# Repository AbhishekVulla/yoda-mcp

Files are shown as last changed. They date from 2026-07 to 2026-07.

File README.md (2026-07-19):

# Yoda

A voice-first care necklace for elderly people living alone. She talks to it. It talks to her caregiver.

**[Demo video](https://www.youtube.com/watch?v=fLG9y0mhrLA)** · Top 5 Finalist, Dell InnovateDash 2026 (Care Corner)

> The wake word is "Jarvis". Espressif only ships a handful of pre-trained wake words and "Yoda" isn't one of them, so the repo kept the original name.

## Why

Singapore's community care services do exist. They are just scattered across portals, hotlines and 20-question intake forms, and the people who need them most are the least likely to get through an app to reach them. Someone who can talk to a necklace does not have to navigate any of that, and her caregiver still makes every decision.

## What it does

**Daily check-in.** The necklace starts a short recovery check-in on its own, tailored to what's on her record. Did you take your heart medicine. How's the cut on your chest. Any tightness or trouble breathing. Her answers become a health incident, and the dashboard turns that into an SBAR clinical handover a caregiver or a paramedic can actually act on.

**Welfare escalation.** If a caregiver can't reach her at the door or by phone, they ping the necklace from the dashboard. It beeps and asks her to respond. Only if she doesn't answer does the camera unlock, and only after the necklace has said out loud that it's turning on.

One rule underneath both: **the AI never acts alone.** Every action it wants to take becomes a request a human approves first.

## Architecture

```mermaid
flowchart LR
  Senior([Senior]) -->|voice| Pendant[Necklace<br/>XIAO ESP32-S3<br/>· firmware/ ·]
  Pendant -->|audio, MQTT+UDP| Cloud[xiaozhi.me<br/>ASR · LLM · TTS]
  Cloud <-->|MCP tool calls| Server[MCP server<br/>· repo root ·]
  Server --> Neon[(Neon Postgres)]
  Dash[Caregiver dashboard<br/>· dashboard/ ·] <--> Neon
  Dash -->|synthesize SBAR| LLM2[OpenAI]
  Pendant <-.->|poll for ping/camera<br/>push JPEG frames| Dash
  Caregiver([Caregiver]) --> Dash
```

The cloud LLM is the only thing that calls the tools. The dashboard and the MCP server never talk to each other directly, they meet at the database.

## The parts that were actually hard

**The MCP server dials out.** A hosted LLM can't reach a tool server sitting on a laptop behind NAT. So `mcp_pipe.py` opens the WebSocket in the other direction, to the cloud's MCP endpoint, and pipes it to a local stdio FastMCP process. No port forwarding, no public IP, no tunnel service.

**The emergency watchdog is a SQL expression, not a worker.** If she starts a health check and then goes quiet, that silence has to become an alert. Instead of a cron job or a background queue, the escalation is derived at query time:

```sql
CASE WHEN status = 'in_progress' AND now() - started_at > make_interval(secs => 25)
     THEN 'emergency' ...
```

The dashboard already polls every 3s, so the escalation just appears. Nothing to schedule, nothing to keep alive, nothing to crash silently.

**Seeing her from anywhere, with zero setup.** The first version needed the caregiver on the same Wi-Fi to reach the necklace's LAN server. Useless in practice. Now the necklace polls the dashboard for commands and pushes JPEG frames up over HTTPS, so everything is outbound. Works on a mobile hotspot, no router config.

**That relay was quietly killing the wake word.** After adding the relay, "Jarvis" stopped triggering. The cause was a fresh TLS handshake every 2 seconds hogging the CPU and starving the on-chip wake-word detector, which needs a steady mic feed. Throttling the idle poll to 15s brought it back. The camera stream still starves it while running, which is fine, that path is caregiver-initiated.

**Privacy is enforced on the device, not the dashboard.** The camera can't be turned on cold. It only unlocks after a ping goes unanswered, and the necklace speaks an announcement before the lens opens.

## What's real and what's mocked

Real: the voice loop, the tool calls, the database, the triage and escalation, the SBAR report, the camera relay, the firmware.

Mocked: the service providers. No Singapore community-care provider (Care Corner, AIC/ICCP, Meals-on-Wheels) exposes a public booking API, it's all phone, email and referral forms. The tools return realistic results and `services.py` keeps a one-function seam to drop in a real `httpx` call the day an API exists.

Also worth saying plainly: the firmware is a custom board overlay on [`78/xiaozhi-esp32`](https://github.com/78/xiaozhi-esp32) (MIT), not a from-scratch stack. The board definition, welfare HTTP API, cloud relay and camera path are mine.

## Repo layout

```
yoda-mcp/
├── yoda_iccp.py          # the 8 tools the cloud LLM can call
├── mcp_pipe.py           # dials OUT to the cloud MCP endpoint
├── health_db.py          # triage + the no-response escalation
├── kb_store.py           # senior profile load/merge (Neon or local file)
├── events.py             # activity matching
├── services.py           # mock provider adapter (the real-API seam)
├── SYSTEM_PROMPT.md      # the agent prompt, pasted into the xiaozhi console
├── test_*.py             # 14 tests
│
├── firmware/yoda-pendant/    # board overlay: config, welfare HTTP API, cloud relay
├── dashboard/                # Next.js caregiver dashboard
│   ├── app/                  # care view, welfare panel, SBAR report page
│   └── lib/                  # Neon queries + OpenAI report synthesis
└── cad/pendant_case.py       # parametric enclosure (build123d) -> printable STL
```

## The tools

| Tool | What it does |
|---|---|
| `get_senior_profile` | Recall who it's talking to. Called first, so it never re-asks what's on file. |
| `begin_health_check` | Open an incident the moment she reports feeling unwell. Starts the silence timer. |
| `complete_health_check` | File the triage with clinical red flags → `mild` / `serious` |
| `match_events` | Top 1-2 activities for her goals and area, excluding ones already requested |
| `request_activity` | Create a **pending request** for the caregiver. Never books directly. |
| `update_knowledge_base` | Save preferences learned in conversation |
| `get_onboarding_questions` | Short sign-up questions, only what isn't already known |
| `book_meal_delivery` | Mock meal booking |

## Run it

**MCP server** (repo root)

```bash
python -m venv .venv && .venv\Scripts\activate
pip install -r requirements.txt
# .env:  MCP_ENDPOINT=wss://api.xiaozhi.me/mcp/?token=...
#        DATABASE_URL=postgresql://...
python mcp_pipe.py yoda_iccp.py
```

Then paste `SYSTEM_PROMPT.md` into the xiaozhi.me console as the agent's role and hit Refresh on the MCP endpoint. Run only one MCP server at a time.

**Dashboard**

```bash
cd dashboard && npm install
# .env.local:  DATABASE_URL=...  OPENAI_API_KEY=...
npm run dev
```

**Tests**

```bash
pytest          # 14 tests: matching, KB merge, services, triage + escalation
```

## Security

`MCP_ENDPOINT`, `DATABASE_URL` and `OPENAI_API_KEY` live in `.env` / `.env.local`, both gitignored and never committed. The device token in `firmware/yoda-pendant/config.h` is a placeholder in this repo. Rotate the MCP token from the console if it ever leaks.

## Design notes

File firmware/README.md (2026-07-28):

# Pendant firmware

A XIAO ESP32-S3 Sense running the [xiaozhi-esp32](https://github.com/78/xiaozhi-esp32) voice
stack, plus a custom board (`yoda-pendant`) that adds the caregiver welfare check.

This folder is an **overlay, not a full firmware tree**. Upstream is ~18k files of MIT code, and
vendoring it here would bury the part that is actually ours. So this holds only our files, applied
onto a clean upstream checkout.

## What's ours

| Path | What it is |
|---|---|
| `yoda-pendant/config.h` | Pin map: I2S speaker (MAX98357A), PDM mic, camera, boot button, cloud relay config |
| `yoda-pendant/config.json` | Build target and sdkconfig (8 MB flash, EN_US, "Jarvis" wake word) |
| `yoda-pendant/yoda_pendant_board.cc` | The board: voice stack, LAN HTTP server, and the cloud relay loop |
| `assets/checking.ogg` | "We're checking on you now" privacy announce, played before the camera arms |
| `assets/door.ogg` | Legacy ping announce |
| `patches/esp32_camera.{h,cc}.patch` | Adds `CaptureToJpeg` and a lean `CaptureJpegStream` for MJPEG |
| `patches/CMakeLists.txt.patch` | Registers `BOARD_TYPE_YODA_PENDANT` |
| `patches/Kconfig.projbuild.patch` | Adds the board to the menuconfig list |
| `scripts/` | Build, flash and serial helpers (Windows) |

## Hardware

XIAO ESP32-S3 Sense: onboard camera (OV2640 or OV3660 depending on the batch, same Seeed pinout),
onboard PDM mic, 2.4 GHz WiFi, USB-CDC.

**MAX98357A I2S amp.** Note the silk labels on the XIAO are not GPIO numbers:

| Amp pin | GPIO | XIAO pad | Notes |
|---|---|---|---|
| LRC / WS | 1 | D0 | |
| BCLK | 2 | D1 | |
| DIN | 3 | D2 | |
| VIN | | 3V3 | |
| GND | | GND | must share ground with the XIAO |
| SD | | *(see below)* | shutdown + channel select, not optional |
| GAIN | | *(leave floating)* | floating gives the default gain |

These three GPIOs are the ones the board actually drives, so they have to match however the amp is
physically wired. If you rewire it, change `config.h` to suit, not the other way round.

**The SD pin is the one that bites you.** It is not just an on/off pin, it also picks the channel, and
the chip reads it as an analog voltage:

- Near 0 V (below ~0.16 V) the amp is in **full shutdown**. I2S keeps streaming, the ESP32 logs look
  perfect, and the speaker is completely silent. This is the classic false alarm: it looks like a
  software bug and it is not.
- Above roughly 1.4 V it plays the **left** channel. Mid voltages select right or a L+R mix.

Most of these breakouts have a pull-up so SD floats high on its own. Do not assume it. If there is any
doubt, jumper **SD to VIN** and the amp is forced awake on the left channel. The firmware sends the
same mono audio on both slots (`I2S_STD_SLOT_BOTH` in `yoda_pendant_board.cc`), so whichever channel
SD selects, there is audio in it.

**Speaker wiring.** The speaker's two wires go under the screws of the green terminal. If your speaker
came with a JST plug on the end, that plug does **not** mate with a screw terminal. Cut it off, strip
the wires, and clamp bare copper under the screws. A plug resting against the terminal reads as
"connected" by eye and passes no current.

PDM mic is on GPIO 42 (clock) and 41 (data). Wake word is "Jarvis", the stock WakeNet
`wn9_jarvis_tts` model. "Yoda" would need Espressif's paid custom training.

### Silent speaker, healthy logs

If the serial log reaches `State: speaking` and prints `<< ...` lines with no `EspUdp` or `MQTT`
errors, the whole software path is fine: mic, ASR, LLM, TTS and audio transport all worked. That says
nothing about which physical pins the audio is leaving on, or what happens after the amp. Work down
this list, in order:

1. **Pin map mismatch.** The three GPIOs above must match how the amp is actually wired. If they
   don't, the chip clocks I2S out of pins with nothing attached and every log line still looks
   perfect. Check this before touching the hardware.
2. **SD pin** at 0 V or floating low, so the amp is shut down (see above).
3. **Speaker not actually clamped** in the screw terminal (see above).
4. **Ground not common** between amp and XIAO.
5. **No power on VIN.**
6. **Blown speaker.** A 1 W driver run at high volume dies quickly, so keep the volume low while
   testing.

A useful splitter: with the amp powered, briefly tap the `DIN` pin to 3.3 V and back. A live amp and a
live speaker will click or pop audibly. Clicks mean the analog side is fine and the problem is
upstream. No clicks at all means the amp is asleep, unpowered, or not connected to the speaker.

## Two ways the caregiver reaches the necklace

**Cloud relay (the one that matters).** The necklace polls the deployed dashboard for pending
commands and pushes JPEG frames back up, both outbound over HTTPS. No port forwarding, no LAN
discovery, no public IP. It works on a mobile hotspot. Configured by `YODA_CLOUD_BASE` /
`YODA_DEVICE_TOKEN` in `config.h`, hitting `/api/device/poll` and `/api/device/frame`.

The idle poll is deliberately slow (15 s). A faster poll means a fresh TLS handshake every cycle,
which starves the on-chip wake-word detector of CPU and stops "Jarvis" triggering at all. That bug
cost a while to find, so the interval is load-bearing, not arbitrary.

**LAN HTTP server (fallback).** Kept for same-WiFi debugging.

| Endpoint | Effect |
|---|---|
| `GET /ping` | Beep and announce, asking her to respond |
| `GET /camera/on` | Privacy announce, then arm the camera |
| `GET /capture` | One JPEG still, only when armed |
| `GET /stream` | Live MJPEG until the client disconnects |
| `GET /camera/off` | Disarm, stream loop exits |

Camera frames are gated behind `/camera/on` by design. The caregiver cannot see anything until the
necklace has said out loud that it is turning on.

## Build from scratch

Needs ESP-IDF v5.5.x (built against 5.5.2).

```powershell
git clone https://github.com/78/xiaozhi-esp32.git
cd xiaozhi-esp32
powershell -File ..\yoda-mcp\firmware\apply-overlay.ps1 -XiaozhiRoot .
python scripts\release.py yoda-pendant
```

The wake word and 8 MB flash config come from `config.json`'s `sdkconfig_append`, so a clean build
is already set to Jarvis with no manual menuconfig.

```powershell
idf.py -p COM5 flash        # COM5 is single-access, close any serial monitor first
pio device monitor -p COM5 -b 115200
```

On boot the log prints the device's LAN IP for the fallback path:
`=== JARVIS WELFARE: device IP = 10.x.x.x ===`

> The `scripts/*.bat` helpers hard-code local paths (ESP-IDF under `C:\Users\...`). They are
> committed as a record of how this machine builds. Edit the paths for another environment, or use
> the raw `idf.py` commands above.

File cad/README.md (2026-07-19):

# Pendant case (XIAO ESP32-S3 Sense)

Parametric enclosure, printed in two parts. Every dimension is a number at the top of
`pendant_case.py`, so a bad test fit is a one-line change and a re-run, not a CAD session.

## Files

`pendant_case.py` is the model. It writes `pendant_base` and `pendant_lid` as both `.stl`
(slice these) and `.step` (edit these). `viewer.html` is a three.js preview, `preview.png`
is a static render.

## Regenerate

```bash
cd yoda-mcp
cad/.venv/Scripts/python.exe cad/pendant_case.py
```

Exports are vertex-merged and watertight-checked on the way out. A non-manifold edge fails
loudly here instead of halfway through a slicer.

## Preview in a browser

```bash
cd yoda-mcp/cad
.venv/Scripts/python.exe -m http.server 8000
# open http://localhost:8000/viewer.html
```

## What it holds

Interior 26 x 36 x 26 mm, outer 30 x 31 x 40 mm. That fits the XIAO ESP32-S3 Sense stack
(21 x 17.8 x 15), a 30 x 20 x 4.2 speaker, and a MAX98357 amp, stacked front to back.

The lid closes on a mid-wall spigot lip plus two diagonal M2 screws. The lip sits in the
middle of the wall rather than flush with the cavity, which keeps it clear of the screw
bosses and avoids the coincident faces that produce non-manifold geometry.

Camera hole is 7 mm (6 mm lens plus clearance), placed high so it clears the lanyard boss.
Three 2 mm holes below it vent the speaker and double as the mic opening. USB-C exits the
bottom edge.

## Printing

PLA, 0.2 mm layers, 3 walls, 15% infill. No supports needed: print the tub open side up and
the lid face down. Two M2 self-tapping screws, 6 to 8 mm.

## Tuning after a test fit

| Symptom | Parameter |
|---|---|
| Board will not drop in, or rattles | `BAYS["compact"]`, `WALL` |
| Camera hole misaligned | `CAM_OFF_X` (right is +), `CAM_OFF_Z` (up is +) |
| USB-C will not seat | `USB_OFF_X`, `USB_OFF_Y`, `USB_W`, `USB_H` |
| Lid too tight or too loose | `GROOVE_CLR` |
| Screws bind | `SCREW_CLEAR`, `SCREW_PILOT` |

`LAYOUT = "breadboard"` swaps in a larger bay if the amp is on a breadboard instead of
soldered.

## Known gaps

No board-retention ledge yet, the closed lid holds the board down. No dedicated antenna
channel either, the flat u.FL antenna tucks against an inside wall. Both are fine at this
size and worth adding once a print confirms the fit.

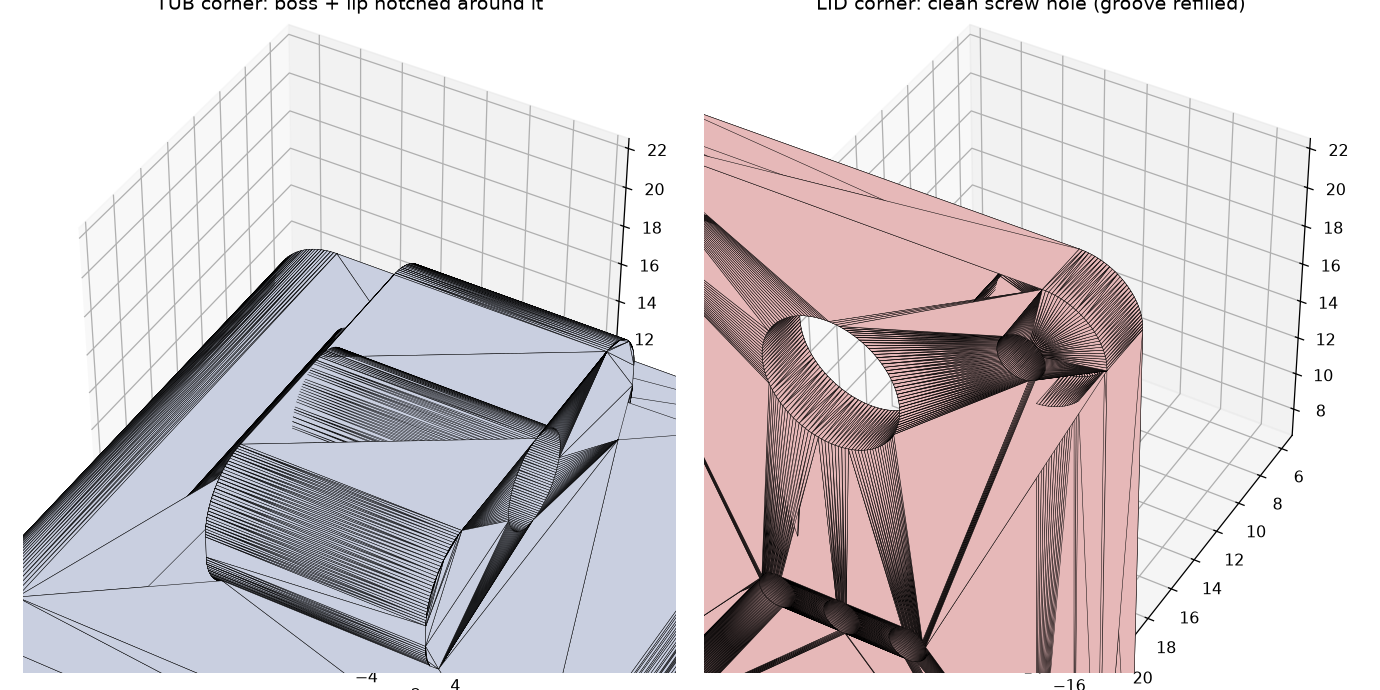
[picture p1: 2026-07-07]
cad/preview.png

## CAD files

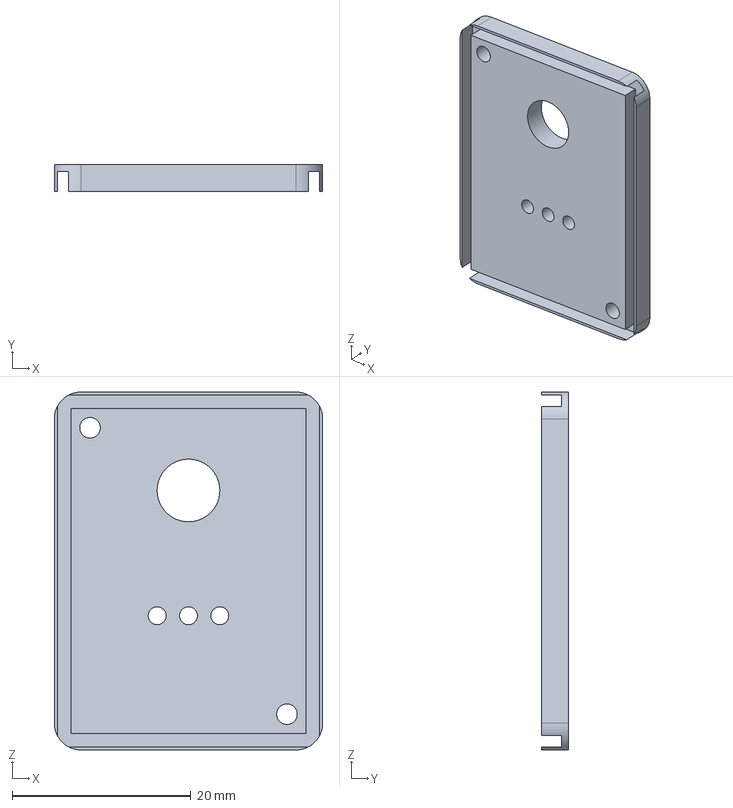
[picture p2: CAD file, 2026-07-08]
cad/pendant_lid.step
30.0 x 3.00 x 40.0 mm

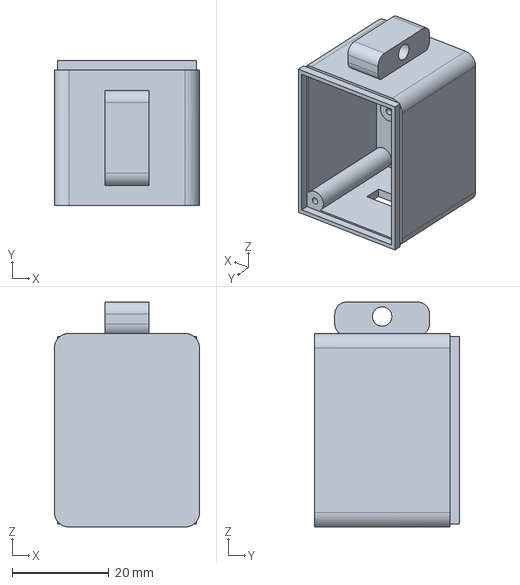
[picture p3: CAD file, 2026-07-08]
cad/pendant_base.step
30.0 x 30.0 x 46.5 mm

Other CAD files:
cad/pendant_base.stl
cad/pendant_lid.stl

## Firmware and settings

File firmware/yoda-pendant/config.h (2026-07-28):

#ifndef _BOARD_CONFIG_H_
#define _BOARD_CONFIG_H_

#include <driver/gpio.h>

// ===================== Yoda Pendant =====================
// Seeed XIAO ESP32-S3 Sense + MAX98357A amplifier + onboard PDM mic + OV2640 camera.
// No display, no LED (base Board provides NoDisplay / NoLed).

// ---------------- Audio ----------------
// Speaker: MAX98357A (I2S standard output).  Mic: onboard PDM microphone.
// Driven by NoAudioCodecSimplexPdm (separate speaker I2S + PDM mic RX).
#define AUDIO_INPUT_SAMPLE_RATE  16000
#define AUDIO_OUTPUT_SAMPLE_RATE 24000

// I2S amplifier. Silk D-labels are not GPIO numbers: GPIO1=D0, GPIO2=D1, GPIO3=D2.
// amp LRC->GPIO1, amp BCLK->GPIO2, amp DIN->GPIO3, VIN->3.3V, GND->GND.
// These must match how the amp is physically wired; if you rewire, update these.
#define AUDIO_I2S_SPK_GPIO_LRCK  GPIO_NUM_1   // LRC/WS on the amp -> GPIO1 (pad D0)
#define AUDIO_I2S_SPK_GPIO_BCLK  GPIO_NUM_2   // BCLK on the amp   -> GPIO2 (pad D1)
#define AUDIO_I2S_SPK_GPIO_DOUT  GPIO_NUM_3   // DIN on the amp    -> GPIO3 (pad D2)

// Onboard PDM microphone (XIAO ESP32-S3 Sense daughterboard)
#define AUDIO_I2S_MIC_GPIO_CLK   GPIO_NUM_42  // PDM clock
#define AUDIO_I2S_MIC_GPIO_DIN   GPIO_NUM_41  // PDM data

// ---------------- Buttons ----------------
#define BOOT_BUTTON_GPIO         GPIO_NUM_0

// ---------------- Camera (OV2640 on XIAO ESP32-S3 Sense, Seeed pinout) ----------------
#define CAMERA_PIN_PWDN   GPIO_NUM_NC
#define CAMERA_PIN_RESET  GPIO_NUM_NC
#define CAMERA_PIN_XCLK   GPIO_NUM_10
#define CAMERA_PIN_SIOD   GPIO_NUM_40   // SCCB SDA
#define CAMERA_PIN_SIOC   GPIO_NUM_39   // SCCB SCL
#define CAMERA_PIN_D7     GPIO_NUM_48   // Y9
#define CAMERA_PIN_D6     GPIO_NUM_11   // Y8
#define CAMERA_PIN_D5     GPIO_NUM_12   // Y7
#define CAMERA_PIN_D4     GPIO_NUM_14   // Y6
#define CAMERA_PIN_D3     GPIO_NUM_16   // Y5
#define CAMERA_PIN_D2     GPIO_NUM_18   // Y4
#define CAMERA_PIN_D1     GPIO_NUM_17   // Y3
#define CAMERA_PIN_D0     GPIO_NUM_15   // Y2
#define CAMERA_PIN_VSYNC  GPIO_NUM_38
#define CAMERA_PIN_HREF   GPIO_NUM_47
#define CAMERA_PIN_PCLK   GPIO_NUM_13
#define XCLK_FREQ_HZ      20000000

// ---------------- Cloud relay (welfare from anywhere, no LAN IP) ----------------
// The necklace polls the deployed dashboard for ping/camera commands and pushes JPEG
// photos up, so the caregiver can check on the senior over the internet. The LAN HTTP
// server (yoda_pendant_board.cc) is kept as a same-Wi-Fi fallback.
#define YODA_CLOUD_BASE   "https://jarvis-care-dashboard.up.railway.app"
#define YODA_DEVICE_TOKEN "REPLACE_WITH_DEVICE_TOKEN_MATCHING_DASHBOARD_ENV"
#define YODA_SENIOR_ID    "mdm-tan"

#endif // _BOARD_CONFIG_H_

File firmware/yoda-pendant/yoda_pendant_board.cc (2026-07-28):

#include "wifi_board.h"
#include "codecs/no_audio_codec.h"
#include "system_reset.h"
#include "application.h"
#include "button.h"
#include "config.h"
#include "mcp_server.h"
#include "esp32_camera.h"

#include <esp_log.h>
#include <esp_http_server.h>
#include <esp_netif.h>
#include <esp_wifi.h>
#include <freertos/FreeRTOS.h>
#include <freertos/task.h>
#include <string>
#include <string_view>

#define TAG "JarvisPendant"

// Pre-rendered announce clips (Opus/OGG), embedded from assets/common/*.ogg.
extern const char door_ogg_start[] asm("_binary_door_ogg_start");
extern const char door_ogg_end[]   asm("_binary_door_ogg_end");
extern const char checking_ogg_start[] asm("_binary_checking_ogg_start");
extern const char checking_ogg_end[]   asm("_binary_checking_ogg_end");

// Shared with the HTTP handlers (the board is a singleton).
static Esp32Camera* s_camera = nullptr;
static volatile bool s_camera_armed = false;

// Yoda welfare-check necklace: XIAO ESP32-S3 Sense + MAX98357A speaker + onboard
// PDM mic + OV2640 camera. Runs the xiaozhi voice stack AND a tiny LAN HTTP server
// so the caregiver dashboard can ping the senior and pull a camera photo on demand.
class YodaPendant : public WifiBoard {
private:
    Button boot_button_;
    Esp32Camera* camera_;
    httpd_handle_t server_ = nullptr;

    void InitializeCamera() {
        camera_config_t config = {};
        config.pin_d0 = CAMERA_PIN_D0;
        config.pin_d1 = CAMERA_PIN_D1;
        config.pin_d2 = CAMERA_PIN_D2;
        config.pin_d3 = CAMERA_PIN_D3;
        config.pin_d4 = CAMERA_PIN_D4;
        config.pin_d5 = CAMERA_PIN_D5;
        config.pin_d6 = CAMERA_PIN_D6;
        config.pin_d7 = CAMERA_PIN_D7;
        config.pin_xclk = CAMERA_PIN_XCLK;
        config.pin_pclk = CAMERA_PIN_PCLK;
        config.pin_vsync = CAMERA_PIN_VSYNC;
        config.pin_href = CAMERA_PIN_HREF;
        config.pin_sccb_sda = CAMERA_PIN_SIOD;
        config.pin_sccb_scl = CAMERA_PIN_SIOC;
        config.sccb_i2c_port = 1;  // keep camera SCCB off I2C0
        config.pin_pwdn = CAMERA_PIN_PWDN;
        config.pin_reset = CAMERA_PIN_RESET;
        config.xclk_freq_hz = XCLK_FREQ_HZ;
        config.pixel_format = PIXFORMAT_RGB565;
        config.frame_size = FRAMESIZE_VGA;
        config.jpeg_quality = 12;
        config.fb_count = 2;  // double-buffer: grab next frame while encoding -> smoother stream
        config.fb_location = CAMERA_FB_IN_PSRAM;
        config.grab_mode = CAMERA_GRAB_WHEN_EMPTY;
        camera_ = new Esp32Camera(config);
        camera_->SetHMirror(false);
        camera_->SetVFlip(false);
        s_camera = camera_;
    }

    void InitializeButtons() {
        boot_button_.OnClick([this]() {
            auto& app = Application::GetInstance();
            if (app.GetDeviceState() == kDeviceStateStarting) {
                EnterWifiConfigMode();
                return;
            }
            app.ToggleChatState();
        });
    }

    // ---- Welfare-check HTTP server (reached directly by the caregiver dashboard over the LAN) ----

    static void AddCors(httpd_req_t* req) {
        httpd_resp_set_hdr(req, "Access-Control-Allow-Origin", "*");
    }

    // GET /ping  -> beep + "someone is at the door" announce
    static esp_err_t PingHandler(httpd_req_t* req) {
        AddCors(req);
        std::string_view checkin(checking_ogg_start, (size_t)(checking_ogg_end - checking_ogg_start));
        Application::GetInstance().PlaySound(checkin);
        ESP_LOGI(TAG, "/ping -> played check-in announce");
        httpd_resp_set_type(req, "application/json");
        httpd_resp_sendstr(req, "{\"ok\":true,\"action\":\"ping\"}");
        return ESP_OK;
    }

    // GET /camera/on -> privacy announce, then arm the camera
    static esp_err_t CameraOnHandler(httpd_req_t* req) {
        AddCors(req);
        std::string_view checking(checking_ogg_start, (size_t)(checking_ogg_end - checking_ogg_start));
        Application::GetInstance().PlaySound(checking);
        s_camera_armed = true;
        ESP_LOGI(TAG, "/camera/on -> announced + armed");
        httpd_resp_set_type(req, "application/json");
        httpd_resp_sendstr(req, "{\"ok\":true,\"action\":\"camera_on\"}");
        return ESP_OK;
    }

    // GET /camera/off -> disarm
    static esp_err_t CameraOffHandler(httpd_req_t* req) {
        AddCors(req);
        s_camera_armed = false;
        ESP_LOGI(TAG, "/camera/off -> disarmed");
        httpd_resp_set_type(req, "application/json");
        httpd_resp_sendstr(req, "{\"ok\":true,\"action\":\"camera_off\"}");
        return ESP_OK;
    }
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

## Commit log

2026-06-16 refactor: human-in-the-loop, Yoda requests, caregiver approves
    Yoda no longer books directly. request_activity creates a PENDING row in the
    new Neon 'requests' table; the caregiver approves/declines on the dashboard.
    - requests_db.py: create/list/decide requests (Neon)
    - yoda_iccp.py: book_aac_activity -> request_activity; update_knowledge_base = prefs only
    - SYSTEM_PROMPT.md: concise, one short question per turn, frame as a request not a booking
    - drop services.book_activity + its test
2026-06-16 docs: README for the monorepo, two-sided architecture, folder structure, request/approval flow
2026-06-18 feat(dashboard): Feature 2 welfare check panel
    Caregiver-initiated ping + camera flow: Ping (door announce) -> Request
    Camera (privacy announce, then arm) -> live MJPEG stream in an <img>, with
    a /capture preload-swap fallback. Talks to the necklace directly over LAN.
2026-06-18 feat(firmware): yoda-pendant board overlay
    Custom xiaozhi-esp32 board for the necklace: voice stack + LAN welfare HTTP
    API (/ping, /camera/on, /capture, /stream MJPEG, /camera/off), Jarvis wake
    word, door/checking announces. Kept as an overlay (board + assets + patches)
    onto a clean upstream checkout rather than vendoring 18k upstream files.
    Includes build/flash scripts and apply-overlay.ps1.
2026-06-18 feat: health triage, escalation & AI clinical report (Features 3 + 3.5)
    Feature 3, voice health check: begin/complete_health_check MCP tools + health_db
    (triage with clinical red-flags; no-response 'emergency' derived at query time, no
    cron). Dashboard surfaces colour-graded alerts (mild/urgent/emergency) with the
    relevant interRAI context inline, plus acknowledge/resolve.
    Feature 3.5, AI clinical report: dashboard-side OpenAI synthesis fuses the acute
    episode with her interRAI record into an SBAR handover (caregiver summary + clinical
    SBAR + paramedic block), cached on the incident row, rendered inline and on a
    printable /report/[id] page. Auto-generates on serious/emergency; strict JSON s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
2026-06-20 feat: cloud-relay welfare (no-IP, see-from-anywhere) + Railway deploy
    Necklace polls the cloud and pushes JPEG frames; the dashboard reads the latest -
    no LAN IP, viewable from anywhere. New device_db + /api/device/{poll,frame} +
    /api/welfare[/frame]; welfare panel reworked to the relay (online status, ping,
    photo) with a same-Wi-Fi LAN-stream fallback. Only surface actually-present interRAI
    diagnoses on alerts. Railway config (railway.json, Node 20 .nvmrc, .railwayignore).
2026-06-20 chore(firmware): sync overlay to latest, cloud relay, speaker GPIO 7/8/9, both-channel codec
    Board now polls the cloud + pushes JPEG frames (welfare from anywhere), single-push
    (never starves the wake word), CaptureToJpeg (correct colors), MAX/NS4168 amp on
    GPIO 7/8/9 with I2S_STD_SLOT_BOTH. Device token is a PLACEHOLDER in config.h (set the
    real one locally to match the dashboard DEVICE_TOKEN env).
    [config.h, yoda_pendant_board.cc]
2026-07-04 feat: Madam Tan rename, smooth same-Wi-Fi camera stream, Care/Welfare header toggle
    - Rename the senior's display name Mdm Tan -> Madam Tan across the dashboard, seed
    profile, and onboarding (TTS mispronounced 'Mdm'); the live Neon DB was updated separately.
    - Welfare: on the same Wi-Fi, arm the necklace and show its smooth /stream MJPEG as the
    primary view (was the slow cloud slideshow); the cloud relay stays the remote fallback.
    - Add a shared Care | Welfare segmented header toggle (screen-tabs.tsx) to both screens.
2026-07-05 feat: Jarvis rebrand + post-op daily check-in reframe (Codex hackathon)
    Rebrand the judge-facing surface Yoda -> Jarvis and reframe the demo into two
    features for the Codex for Healthcare hackathon (8-9 Jul 2026):
    - Feature 1 (Daily Check-in): SYSTEM_PROMPT reframed to a proactive post-op
    heart-bypass day-2 wellness check -> health incident -> SBAR report;
    mdm-tan.json profile rewritten to a post-CABG history.
    - Feature 2 (Manual Check Escalation): welfare panel reworded to the safety
    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
2026-07-07 feat: laptop voice bridge -- speak Jarvis's replies through the laptop
    The necklace speaker/amp shipped wrong, so jarvis_speak.py taps the pendant's
    USB serial and speaks each "<<" line (Jarvis's TTS text) out the laptop speaker
    via streaming cloud TTS (Cartesia default, ElevenLabs swappable). Read-only, no
    firmware/cloud change; if TTS fails the serial log still prints. Skips the
    "<< % tool_name" tool-call markers.
    [jarvis_speak.py]
2026-07-07 feat: parametric 3D-printed pendant enclosure (build123d)
    Shrinks the case to the XIAO ESP32-S3 Sense stack + MAX98357 amp + small speaker
    (27 x 26 x 37 mm, ~1/7 the old project box). Mid-wall snap lip + lid groove + 2
    screws, 7mm camera hole, 3-hole speaker/mic grille, centered bottom USB-C slot,
    solid back, lanyard loop. Exports are vertex-merged + watertight-checked so they
    slice clean (no non-manifold edges). Includes a three.js viewer + README.
    [pendant_base.step, pendant_base.stl, pendant_lid.step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]
2026-07-08 fix(cad): enlarge bay to fit speaker + board + amp (26x36x26)
    v1 print came out too small -- the 21mm depth couldn't stack the 15mm board +
    4.2mm speaker + amp, and the footprint was tight against the 30x20mm speaker.
    Bumped the interior to 26 x 36 x 26mm (outer 30 x 31 x 40). Fit-checked all
    three components + stack depth.
    [pendant_base.step, pendant_base.stl, pendant_lid.step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]
2026-07-19 docs: README, license, and contributor setup
    Rewrite the README around the architecture diagram, the demo video, and the
    design decisions worth reading: the MCP server dialling out to the cloud
    rather than being reachable, the emergency watchdog derived in SQL instead
    of a background worker, the outbound relay that needs no port forwarding,
    and the wake-word starvation fix.
    Add an MIT license with attribution for the xiaozhi-esp32 firmware overlay,
    .env.example for both the server and the dashboard, and a CI workflow that
    runs the test suite without needing any secrets.
    Correct the firmware README's speaker pin map. It documented GPIO1/2/3 but
    the board actually uses GPIO7/8/9 on pads D8/D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
2026-07-28 fix(firmware): correct I2S speaker pins to GPIO 1/2/3
    The board config drove I2S on GPIO 7/8/9 while the amp is wired to
    GPIO 1/2/3, so audio was clocked out of unconnected pins. The voice loop
    logged normally the whole time and the speaker stayed silent.
    Point LRC/BCLK/DIN at GPIO 1/2/3 to match the wiring, document the SD and
    GAIN pins that were missing from the pin table, and add a triage list for
    the silent-speaker-with-healthy-logs case.
    [config.h, jarvis_speak.py, yoda_pendant_board.cc]
